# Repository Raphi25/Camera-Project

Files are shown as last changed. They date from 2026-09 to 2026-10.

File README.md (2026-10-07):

# Camera-Project
This master's project investigates the development of a low-cost wearable camera system intended to support caregivers by capturing images throughout the wearer's daily life. The system can take images in 30 second intervals in different settings while remaining lightweight, robust, serviceable, inexpensive and long battery life.

## Current firmware and shared App

The current firmware is in [Development Board Prototype/Code](Development%20Board%20Prototype/Code) and [Breadboard Prototype/Code](Breadboard%20Prototype/Code). Open either Code folder and build with `idf.py build`. Dependencies are restored by the ESP-IDF component manager; generated build output and Python environments are excluded.

Both projects use the single [App](App) folder. Run its `Setup_App.cmd` and `Launch_Source.cmd`, or build the Windows executable with `Build_GUI_App.cmd`. Each firmware folder also has launch and build shortcuts. Local passwords and settings are not part of the repository.

## Architecture

Explore the system, firmware, and desktop application interactively:

[Open the interactive architecture explorer](https://raphi25.github.io/Camera-Project/project-architecture.html)

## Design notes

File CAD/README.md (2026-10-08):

This folder contains the STL gcode files needed to make the PCB Case.

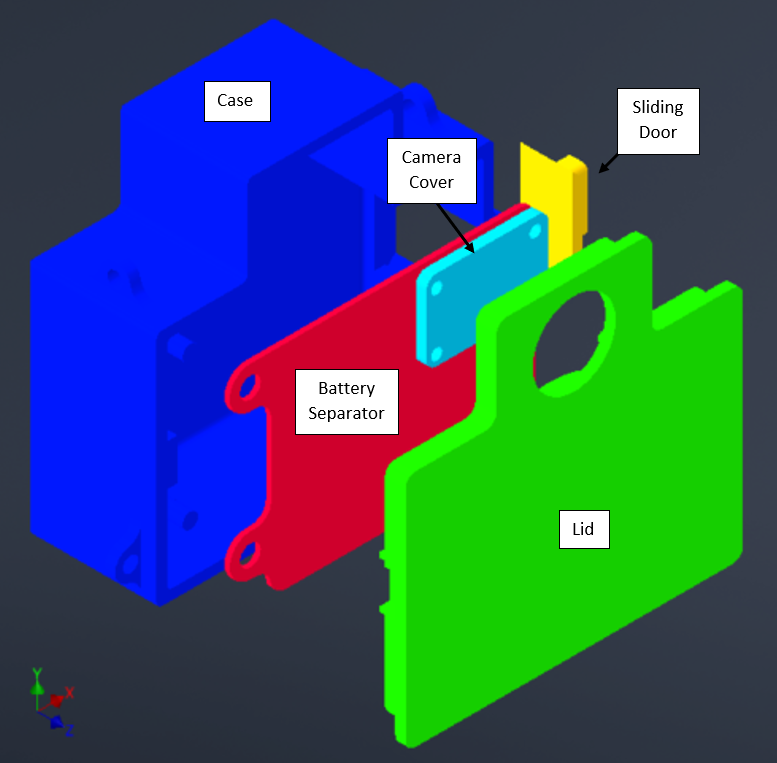
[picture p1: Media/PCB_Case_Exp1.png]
PCB Case


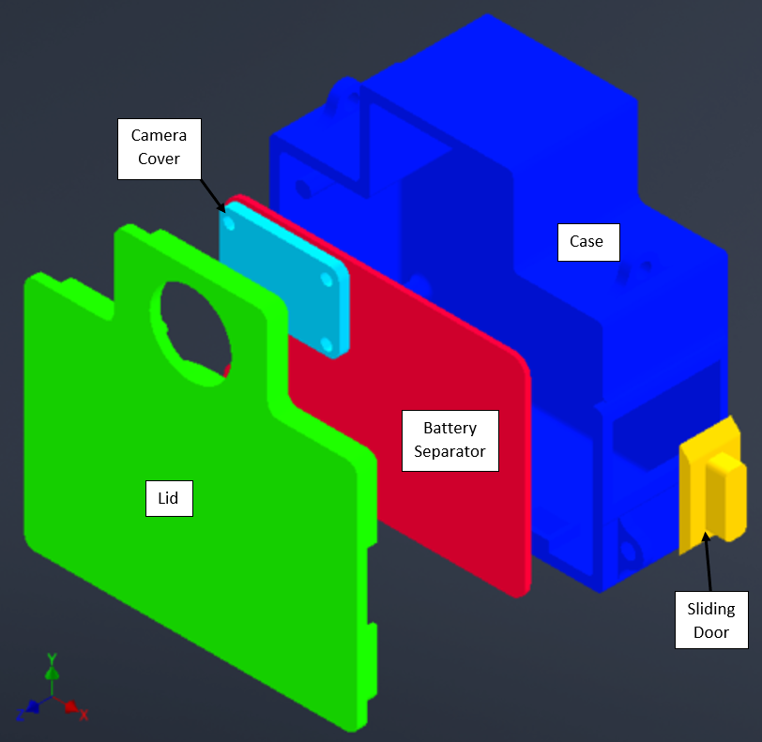
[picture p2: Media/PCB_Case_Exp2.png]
PCB Case


To insert the magnet and receiver coil into teh Lid of teh PCB Case, the print has to be paused at 79-80% percent, pay attention close attention when the 3D printer.

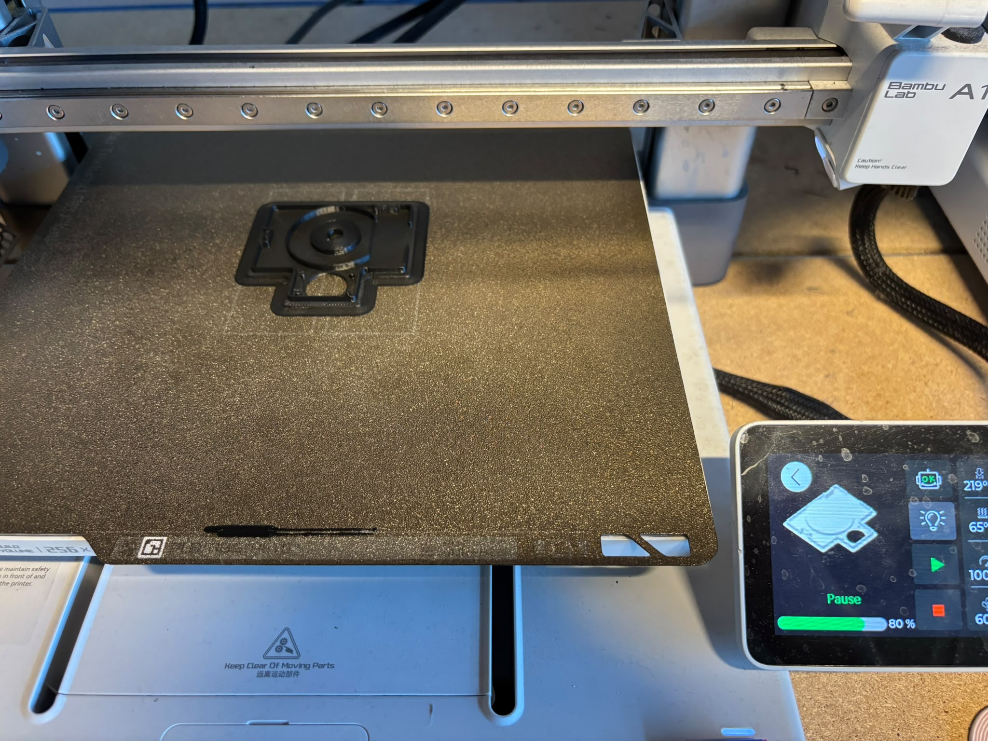
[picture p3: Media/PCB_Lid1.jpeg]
Pause Lid print


The magnet should be able to fit into the central hole and the wireless coil needs to be gently press fitted into the print.

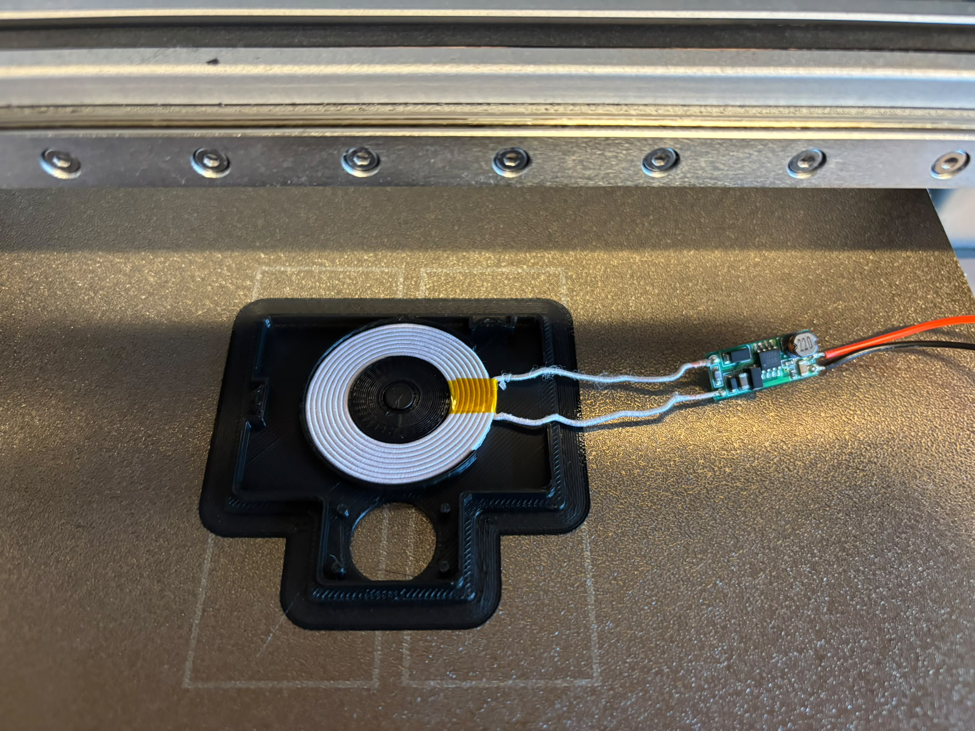
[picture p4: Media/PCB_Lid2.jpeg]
Insert magnet and receiver coil


Once that is done, resume the printing process.

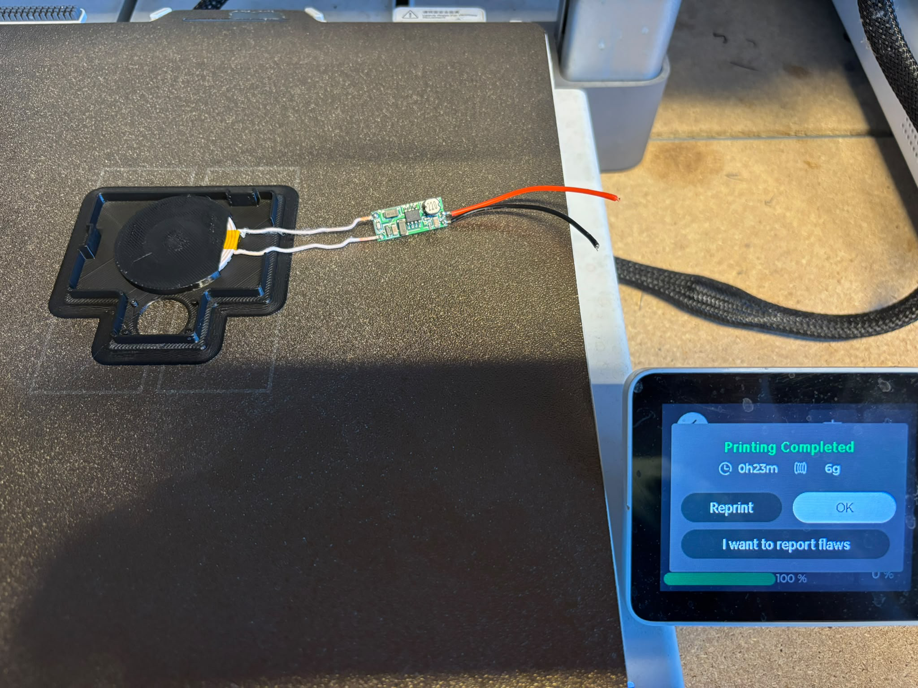
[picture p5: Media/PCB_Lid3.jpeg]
Resume print


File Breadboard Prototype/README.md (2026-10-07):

This folder contains the Code, BOM, storage test results, CAD file for the camera module holder, as well as the code and results for the Blur test.

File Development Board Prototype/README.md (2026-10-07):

This folder contains the Code, BOM, storage test results, CAD files for the case, as well as the code and results for the IMU test.

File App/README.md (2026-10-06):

Shared Camera App
=================

This folder contains the single desktop application used by both sibling
firmware projects: Development Board Prototype and Breadboard Prototype. It will also be the single desktop application used by PCA once its delivered and up and running.

RUN
Double-click Launch_GUI.cmd or BreadboardCameraGUI.exe. Python and ESP-IDF
are not required for the packaged executable. Both firmware projects also
contain Launch_GUI.cmd shortcuts to this same application. On a fresh
installation without a password store, the initial password is ChangeMe123!.

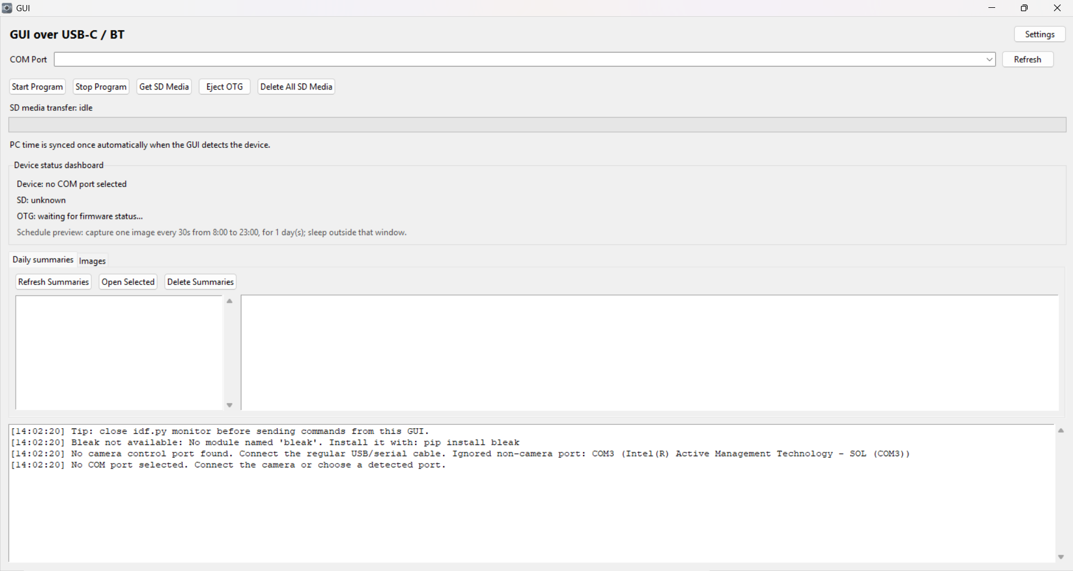
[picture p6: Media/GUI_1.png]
GUI main screen


Select the connected board's COM port or BLE connection inside the app. Click refresh, it will automatically detect the project with an ESP32-P4, no project selection is required.

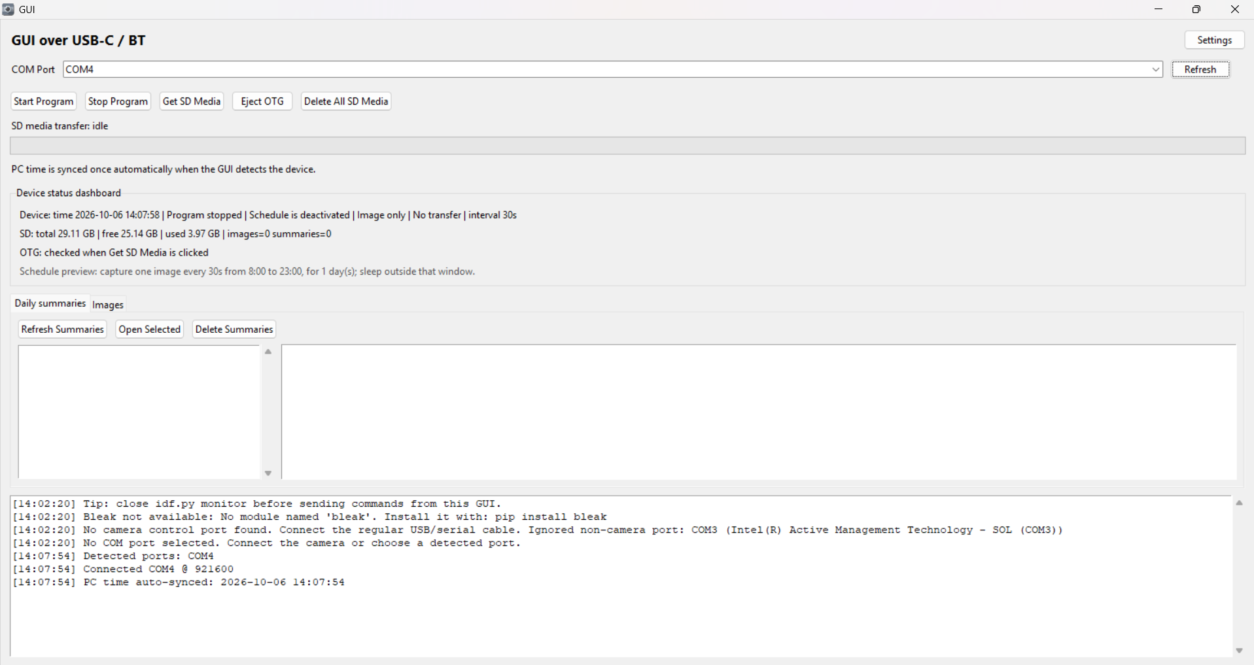
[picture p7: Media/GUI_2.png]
GUI main screen after board is detected


Once project is detected, the Device status dashboard will show the device time, wether a programm is active or not, the schedule of the device, the capture interval. Next, the GUI shows the total free and used space on sd card, and how many images and summaries are already present. Below that teh GUI shows wether the device has an OTG cable attached, for rapid transfer of files.

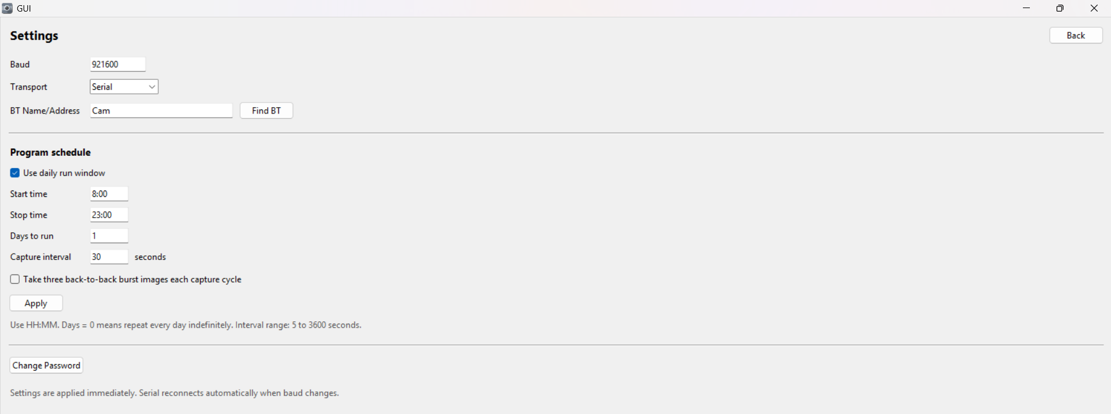
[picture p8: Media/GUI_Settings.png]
GUI settings


When clicking on Settings, certain parameters can be configured, such as mode of transport, Bluetooth name, Program schedule, and wheveer the device should be in normal mode or burst mode. Clicking Apply will confirm teh schedule.

Password can also be changed. Password is needed to login and the transfer or deletion of imagesa and summaries.

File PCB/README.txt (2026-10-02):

This folder contains the Schematic, PCB design and BOM of the device, as well as the datasheets of the parts used for the PCB.

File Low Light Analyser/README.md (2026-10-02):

# OV5647 low-light image analysis

Run the full pipeline with the dataset's current location and the default centered 50% crop:

```powershell
python analyze_low_light.py
```

Use a different normalized crop (`x y width height`) or output folder:

```powershell
python analyze_low_light.py --crop 0.35 0.35 0.30 0.30 --output my_results
```

The script expects one folder per lux level, named like `35LUX`. Each folder can contain any positive number of images; different lux folders may have different image counts. It creates per-image and per-lux CSV files, a formatted Excel workbook with charts, a PNG quality plot, average images, and repeat-standard-deviation maps. Between-repeat standard deviation is unavailable for a folder containing only one image.

Noise is estimated from the high-frequency residual after Gaussian smoothing. This reduces contamination by broad scene gradients, though textured content can still increase the estimate. Repeat variability is pixelwise standard deviation across unregistered repeats, so the camera and scene should remain fixed.

## Separate grayscale and colour-chart analysis

The chart analyzer is a practical, separate-chart, ISO 19093-inspired workflow. It does not claim full ISO 19093 conformity.

Arrange captures as follows:

```text
chart_dataset/
  grayscale/35LUX/image1.jpg ... image5.jpg
  grayscale/75LUX/image1.jpg ... image5.jpg
  colorchecker/35LUX/image1.jpg ... image5.jpg
  colorchecker/75LUX/image1.jpg ... image5.jpg
```

Edit `chart_config.json` so each chart's four normalized corner coordinates describe, in order, its top-left, top-right, bottom-right and bottom-left corners. Coordinates range from 0 to 1 relative to image width and height. The supplied defaults are placeholders. Use the generated diagnostic overlays to confirm every numbered ROI lies inside the intended patch.

Run without calibrated references:

```powershell
python analyze_test_charts.py "C:\path\to\chart_dataset"
```

Run with calibrated patch data:

```powershell
python analyze_test_charts.py "C:\path\to\chart_dataset" `
  --gray-reference grayscale_reference.csv `
  --color-reference color_reference.csv
```

Copy and complete `grayscale_reference_template.csv` with measured relative luminance or reflectance. Copy and complete `color_reference_template.csv` with measured CIELAB reference values. OECF exposure-proxy columns and ΔE76 are only produced when those references are supplied.

Outputs include per-image patch measurements, lux/patch summaries, grayscale OECF/noise/SNR plots, colour chroma/noise/SNR/ΔE plots, diagnostic patch overlays, CSV files and a formatted Excel workbook.

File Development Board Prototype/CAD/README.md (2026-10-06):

This folder contains the STL and gcode files needed to construct the Case for the Development Board Prototype.

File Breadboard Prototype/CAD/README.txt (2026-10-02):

Servo Top is used for Image Quality Test and Blur Test.
For Blur Test, fit the piece on the servo hand.

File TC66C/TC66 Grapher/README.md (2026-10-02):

# TC66 Grapher

Graphs `Current (A)` over `Time` from TC66 CSV or Excel recordings. It also
creates a text report containing the minimum, maximum,
average, total current drawn, projected consumption per 24 hours, and separate
time-weighted average currents while the camera is active and asleep. CSV,
XLSX, XLSM, and legacy XLS files are supported.

Camera state is determined from the configured daily schedule. By default, the
camera is asleep from 23:00 until 08:00 and active from 08:00 until 23:00. To
use a different schedule:

```powershell
.\.venv\Scripts\python.exe plot_tc66.py recording.csv --sleep-start 22:30 --sleep-end 07:30
```

If a sampling interval crosses a scheduled transition, the calculation splits
that interval at the transition. The report shows the measured duration of
each state alongside its average current.

The graph labels every hour on the X-axis.

The recording is automatically cut off at battery shutdown. Shutdown is
detected when voltage is at or below 0.05 V and current is at or below 0.001 A
for 10 consecutive samples. Once confirmed, the cutoff moves back through the
immediately preceding zero-current samples to the first shutdown sample. The
shutdown samples and all later data are excluded from both the graph and
summary statistics.

## Setup

```powershell
python -m venv .venv
.\.venv\Scripts\python.exe -m pip install -r requirements.txt
```

## Run

With no arguments, the newest recording in `Excel files` is used:

```powershell
.\.venv\Scripts\python.exe plot_tc66.py
```

Or choose a file and output path:

```powershell
.\.venv\Scripts\python.exe plot_tc66.py "Excel files\2026-08-20.csv" --output tc66_graph.png
```

The graph defaults to `<input>_graph.png` and the report defaults to
`<input>_summary.txt`. Choose a different report path with `--summary`.

For an Excel workbook, the first sheet is used by default. Select another sheet
by name or zero-based index:

```powershell
.\.venv\Scripts\python.exe plot_tc66.py recording.xlsx --sheet Measurements
```

The input must contain the columns `Time`, `Voltage (V)`, and `Current (A)`.

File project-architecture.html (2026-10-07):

DEVELOPMENT BOARD PROTOTYPE 1

# How the camera system fits together

Explore the hardware, capture pipeline, and desktop application. Select a component to see its role and source files.

Control & applicationCapture & hardwareStorage & filesDashed connection = optional, currently disabled

Current behavior · 7 October 2026

Stop Program: pause → wait for capture and saves → write summary. Burst: three images with individual orientation samples. Repeated summaries: preserve earlier orientation entries. GUI: shared in ../App.

Scroll to zoom · Drag background to pan · Click a component for details

SYSTEM CONTEXT

## An autonomous camera

Works offline. Each view can be exported as a vector SVG. Original architecture notes (September 2026) →

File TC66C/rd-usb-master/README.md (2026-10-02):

Web GUI for RuiDeng USB testers (UM34C, UM24C, UM25C, TC66C)
==

Simple web GUI written in Python 3. Measurements are stored in sqlite database. Tables and graphs are supported.
Live preview and graphing is also available.

Tested on UM34C/UM24C/UM25C/TC66C.

Based on https://github.com/sebastianha/um34c

Requirements
--

- UM34C/UM24C/UM25C - meter connected via regular Bluetooth
- TC66C - meter is using BLE instead of regular bluetooth so pairing will not work nor RFCOMM will
    - BLE has limited support on desktop devices, see used library for supported platforms and versions:
      https://github.com/hbldh/bleak#features
- TC66C USB - meter connected with USB
    - Meter connected with USB exposes itself as serial port
- UM34C/UM24C/UM25C Serial/COM port method - meter can be connected as serial port
    - Pairing with Windows Settings works fine. Pin is 1234. After successful pairing some serial ports are
      installed. In my case two. One of them works.
    - On Linux `rfcomm` and `hcitool` can be used (both provided by bluez package)
        - Retrieve bluetooth address with `hcitool scan`
        - Bind retrieved address to serial port with `rfcomm bind 0 aa:bb:cc:dd:ee:ff`.
          This step is not persistent. Serial port will disappear after reboot. Also, rd-usb needs to
          have permissions to use /dev/rfcommX.

Installation
--

### Binaries (Win x64 only)

- Download from [releases](https://github.com/kolinger/rd-usb/releases)
    - **rd-usb-x.exe** is CLI web server application. GUI is provided by web browser.
      Run executable and web server will be shortly spawned on address http://127.0.0.1:5000.
    - **rd-usb-install-x.exe** is installer of standalone GUI application. Works without web browser.
      Embedded browser is used instead. External web browser still can be used with address (see above).
- Application will be probably blocked by Microsoft SmartScreen. For unblock click `More info`
  and `Run anyway`. I don't have certificate for signing and application does not have any
  reputation so Microsoft will block by default.

### Source code

1. Python 3.11 or newer is required
2. Download `rd-usb-source-x.zip` from [releases](https://github.com/kolinger/rd-usb/releases)
   or `git clone https://github.com/kolinger/rd-usb.git`
3. Install requirements
    - For GUI: `pip install -r requirements.txt`
    - For headless `pip install -r requirements_headless.txt` this version doesn't
      contain dependencies for embedded browser GUI. This is useful if you plan to use CLI/webserver only.
      It's also useful on ARM SBCs.
    - If you encounter failing installing of `pendulum` library then you may need different set of requirements.
      [See bellow for details](#pendulum-issue).\
      In this case use `pip install -r requirements_headless_new.txt` as workaround.
    - If you encounter failing installation of `pybluez` then make sure you have `libbluetooth` dependency installed.\
      For Debian based distribution this means `apt-get install libbluetooth-dev`.\
      For Windows you need Microsoft Visual C++ 14.0 or greater distributed via 
      [Microsoft C++ Build Tools](https://visualstudio.microsoft.com/visual-cpp-build-tools/).
    - There is also currently issue with `pybluez` installation where it fails due to pip version. 
      Make sure you are not using pip 24.x or newer, pip 23.x works fine, if you have newer pip version you can
      downgrade to latest 23.x for example `C:\Python\python.exe -m pip install --upgrade pip==23.3.2`
4. Run with `python web.py` - this will spawn web server on http://127.0.0.1:5000, port can be changed
   with first argument: `python web.py 5555`

For additional arguments/options use --help: `python web.py --help`.

On Windows `python` can be found in Python's installation folder as `python.exe`.
For example replace `python web.py` with `C:\Python\python.exe web.py`
and `pip install -r requirements.txt` with `C:\Python\python.exe -m pip install -r requirements.txt`.

On Linux use `python3` and `pip` inside [virtual environment](https://docs.python.org/3/library/venv.html) (venv).

Usage
--

**UM34C/UM24C/UM25C Bluetooth**

1. Select your device version.
2. Name your session. For example 'testing some power bank'. This is
   used to separate multiple measurements from each other.
3. Select sample rate. Faster sample rate will result in more accurate data but also
   will create a lot more data. For short measurements use faster sample rate. For longer
   use slower rate. Choose carefully.
4. Select UM34C/UM24C/UM25C from devices and follow with Setup link.
    1. If previously connected you can initiate Setup again by clicking on current Bluetooth address
5. Scan for devices and select your device from list by clicking on it
6. After this you can connect simply by using Connect button. Setup is required only for new/different device.
7. Connection will be hopefully successful, and you will see live measurements in graph.
   Otherwise, read log for error messages.

The 100ms and 250ms polling period (‘sample rate’) is misleading since only some meters support polling this quick,
and it seems that all meters have estimated internal sample rate of 2 Hz (500ms) thus even if the meter supports
polling at 10 Hz / 100ms (like the TC66C over USB, while the UM24/25/34 has estimated polling rate up to 3 Hz) this
isn't useful since the extra samples are just duplicates of previous sample. In the original implementation the
polling period wasn't polling period but the gap between samples, that's why in past the 100ms/250ms value did have
meaningful purpose, but currently these options are essentially without purpose and left as legacy.

**TC66C Bluetooth**

1. Make sure your OS is supported and has bluetooth with BLE support (Bluetooth Low Energy)
2. Rest is same as other devices. See above.

**Bluetooth issues**

If you have Bluetooth issues then try to close rd-usb, unplug/plug USB meter and start rd-usb again. Bluetooth can be
sometimes funny and just refuses to work without any reason. If this doesn't help check proximity of your PC and USB
meter, sometimes moving USB meter real close can resolve Bluetooth issues.

Also make sure no other connection to the meter exists, like no other application is connected to the meter,
the RFCOMM isn't bound, if any other connection exists this may break the ability to use or even see the meter
from rd-usb.

If you find trouble connecting to the UM34C/UM24C/UM25C via the direct Bluetooth method then try
to use the UMxxC Serial method, where you need to first pair (in Windows) or use rfcomm bind (Linux),
see [Requirements](#Requirements) above for details.

**TC66C USB or UM34C/UM24C/UM25C Serial/COM port method**

1. Select UM34C/UM24C/UM25C with Serial suffix.
2. Follow Setup link to find your serial port or click Connect if you already have port selected.
3. Rest is same as other devices. See above.

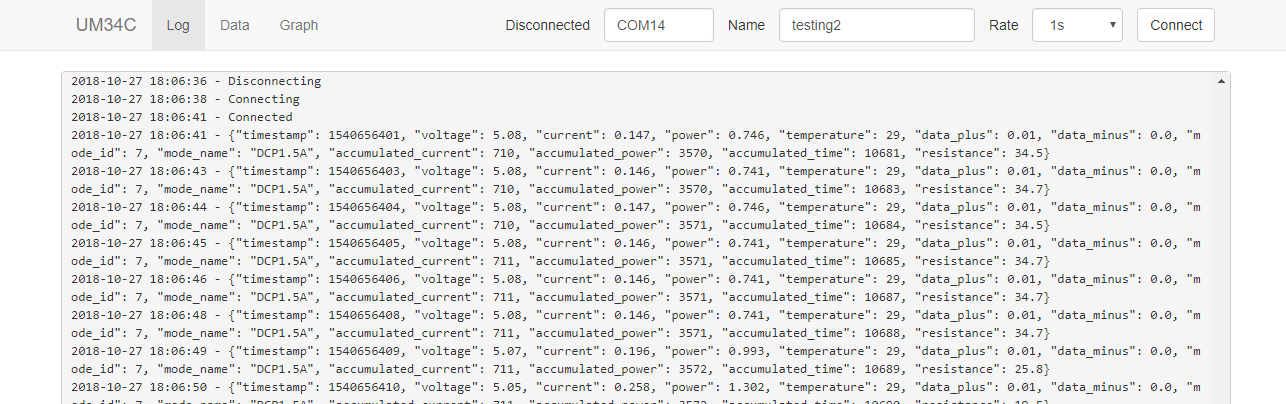
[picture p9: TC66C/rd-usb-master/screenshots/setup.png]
setup


Graphs
--

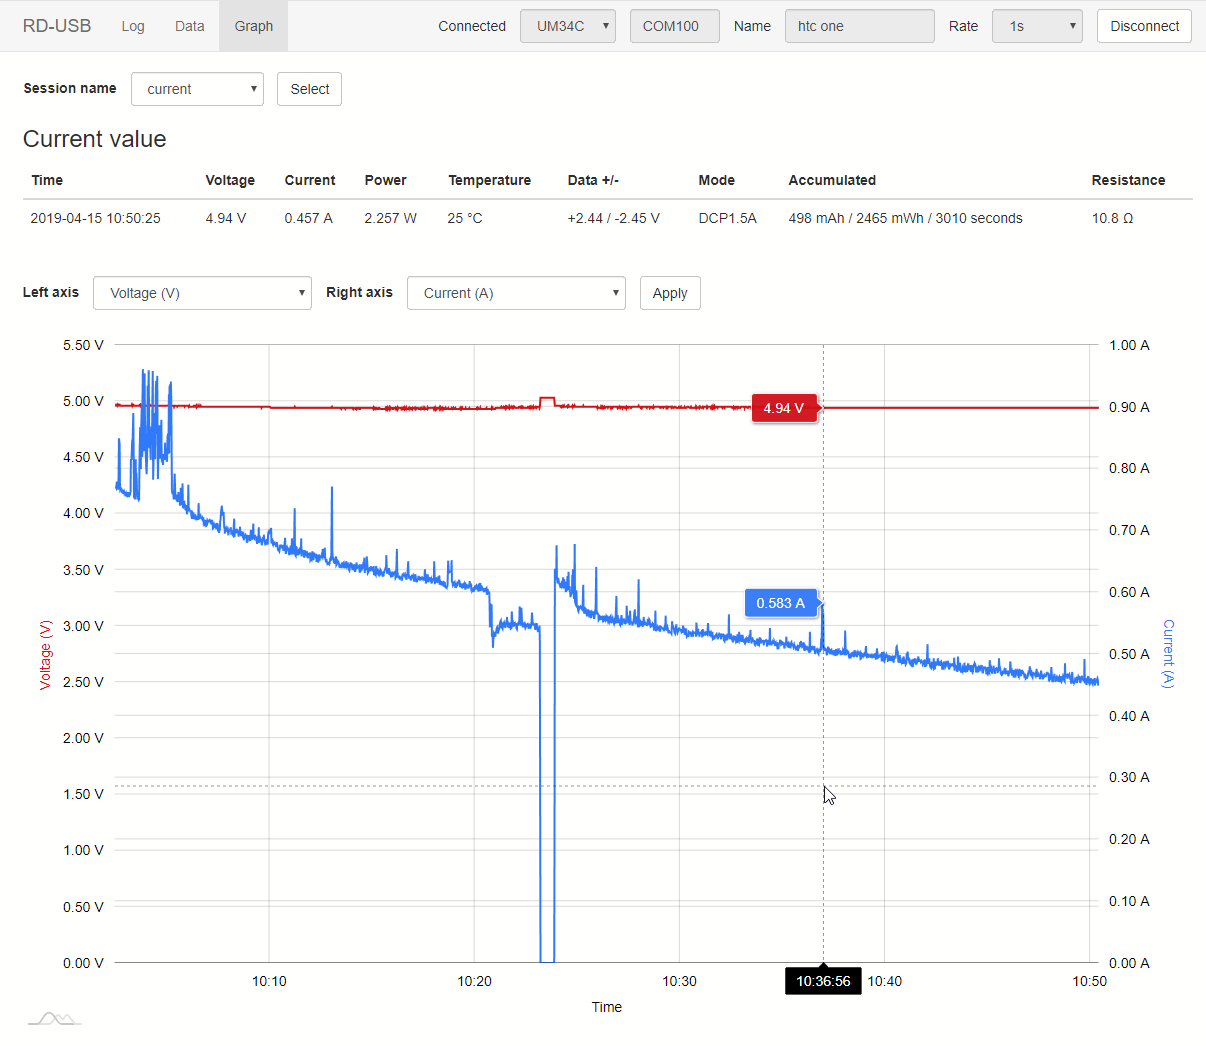
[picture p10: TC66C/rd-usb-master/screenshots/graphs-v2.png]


Tables
--

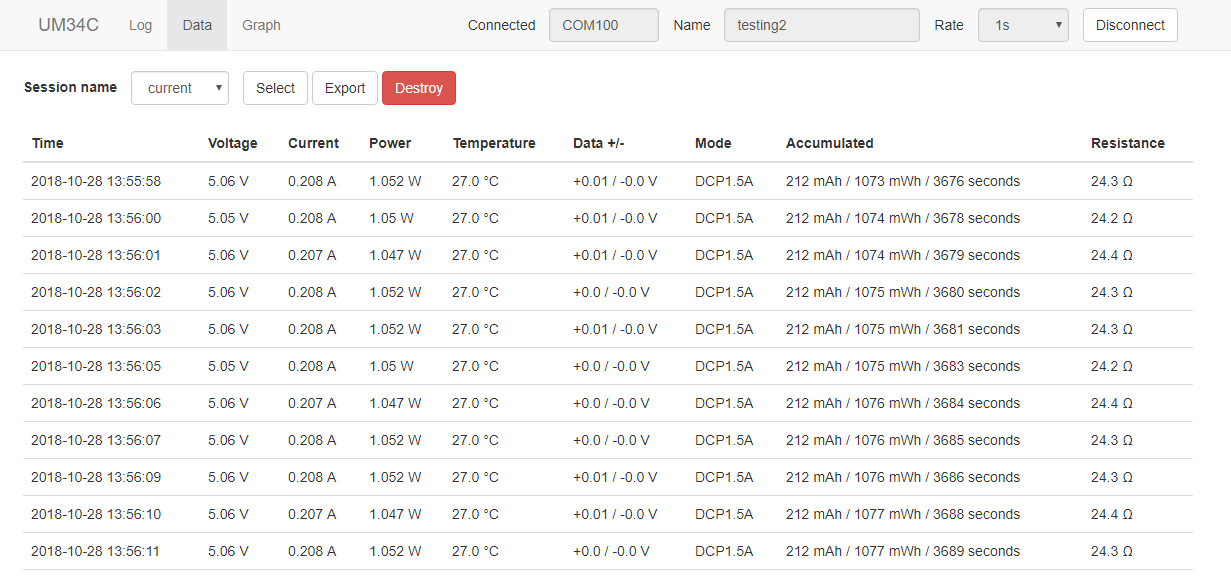
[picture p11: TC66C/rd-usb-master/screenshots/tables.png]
tables


Pendulum issue
--------------

There is known issue with library named `pendulum` (used for date and time) when used together with 
newer Python versions. This issue is triggered when installing requirements via pip and looks
something like this:

```
...
Building wheel for pendulum (pyproject.toml) did not run successfully.
...
ModuleNotFoundError: No module named 'distutils'
...
```

If your installation via pip fails due to this then the solution is to install different version of dependencies.
Specifically `pip install -r requirements_headless_new.txt` should fix this issue.

This issue is solved with version `>=3.0.0` of this library. Unfortunately as of now
version `3.0.0` has other compatibility issues (specifically failing Rust compilation
on systems that don't have prebuilt wheels) thus that's why `<3.0.0` is used by default.

Multiple instances
------------------

If you want to use multiple instances for multiple USB meters then you need to do some adjustments to separate these
instance from each other. As default all instances share the same port thus you can't use multiple USB meters.

This can be easily fixed by changing the port, the port is first argument, without any argument `5000` is used.
We can use default `5000` for first instance and then increment port for each additional instance.

Examples:
- `"C:\Program Files\rd-usb\rd-usb.exe" 5001` for Windows GUI
- `"C:\somewhere\rd-usb.exe" 5001` for Windows standalone binary
- `"C:\Python\python.exe" web.py 5001` for Windows Python
- `/some/python web.py 5001` for Linux

This way you can use multiple instances with multiple USB meters but all data and settings are shared together.

It may be beneficial to separate instances completely including all data and settings. For this extra parameter
`--data-dir` is required, for details see **Custom data directory** section bellow. This parameter expects directory
where all data and settings will be placed. If you combined `--data-dir` and port then you can have independent
instances.

Examples:
- `"C:\Program Files\rd-usb\rd-usb.exe" 5001 --data-dir C:\some\place\for\data` for Windows GUI
- `"C:\somewhere\rd-usb.exe" 5001 --data-dir C:\some\place\for\data` for Windows standalone binary
- `"C:\Python\python.exe web.py" 5001 --data-dir C:\some\place\for\data` for Windows Python
- `/some/python web.py 5001 --data-dir /some/place/for/data` for Linux

On Windows it may be handy to make shortcut for this - just copy existing shortcut and add the parameters at the end of
Target field separated by space like the first examples. Then you have easy access to your second instance.

Docker
--

Experimental Docker container exists. Bluetooth isn't officially supported in Docker so there is need to pass special
arguments to Docker to make it work - there are also caveats that different system may need extra system changes to
make Bluetooth in Docker work.

**Ubuntu/Debian/Raspbian caveats** - you need to load custom Docker AppArmor policy and add extra argument for Docker 
to use this policy instead of the default one. 

In terminal:
```
sudo wget https://raw.githubusercontent.com/kolinger/rd-usb/master/docker/docker-ble -O /etc/apparmor.d/docker-ble
sudo apparmor_parser -r -W /etc/apparmor.d/docker-ble
```

This may be sometimes unnecessary, but it won't hurt.
Thanks to @thijsputman for his work on [docker-ble](https://github.com/thijsputman/tc66c-mqtt/blob/main/docker/docker-ble).

**Other Linuxes caveats** - unknown - if you know, let me know. The principe is the same but details may differ. 
If you use AppArmor then you may need custom policy otherwise Bluetooth won't work.

**Don't forget** to mount `/opt/rd-usb/data` via volume otherwise you will lose all your data when container gets 
recreated/updated.

**docker-compose.yml**

```
version: '3.7'
services:
  rd-usb:
    container_name: rd-usb
    image: kolinger/rd-usb:latest
    restart: unless-stopped
    security_opt:
      - apparmor=docker-ble
    environment:
      - TZ=Etc/UTC # change your timeozne (TZ identifier here), for example Europe/London
      - ARGS=
    volumes:
      - /var/run/dbus/system_bus_socket:/var/run/dbus/system_bus_socket
      - /some/place/to/store/data:/opt/rd-usb/data
    # you need something like these examples if you want to use serial port based communication
    #devices:
    #  - /dev/ttyUSB0
    #  - /dev/rfcomm0
    network_mode: host
```

Change `/some/place/to/store/data` to your liking.

If you want to use TC66C USB or UMxxC Serial then you also need to pass specific serial device to docker. For TC66C USB
it would be something like /dev/ttyUSB0 and for UMxxC Serial something like /dev/rfcomm0.

Optional arguments for `web.py` can be passed to `ARGS` environment variables - for example `ARGS=1888` will 
change listening port to 1888, `ARGS="1888 --prefix /rd-usb"` will set path prefix for proxy purposes.

Custom data directory
--
Custom data directory can be specified with `--data-dir` option.

For example `rd-usb.exe --data-dir C:/rd-usb` will place all configuration and data files in `C:/rd-usb` directory.
This can be used together with shortcut, just make sure you escape path with quotes properly, for example:
`"C:\your\path\rd-usb.exe" --data-dir "C:\your\path\data"`.

Custom export
--

Application has basic CSV export built-in. For more advanced use-cases external script can be used.

External program/script can be specified with `--on-receive` option.
This script will be executed when new data is received.
New measurements are provided as JSON file. Path of this file is provided as first argument.

For managing overhead another option `--on-receive-interval` is available (default value is 60).
This number specified how often is external script called (in seconds, default value is every minute).
Value 0 means script will be called for every new measurement as they happen.
Script is not called when no new measurements are available.

CLI example: `python web.py --on-receive on-receive.sh`

See `on-receive.sh` or `on-receive.cmd` files for more information how implement this program/script.
Also `on-receive-python-example.cmd` and `on-receive-python-example.py` show more extended example how to call python.

Example structure of JSON file:

```
[
    {
        "timestamp": 1599556295,
        "voltage": 5.12,
        "current": 0.0,
        "power": 0.0,
        "temperature": 25,
        "data_plus": 0.0,
        "data_minus": 0.0,
        "mode_id": 7,
        "mode_name": "DCP1.5A",
        "accumulated_current": 0,
        "accumulated_power": 0,
        "accumulated_time": 0,
        "resistance": 9999.9,
        "name": "measurement name"
    },
    ...
]
```

Reverse proxy
--

If you like to have HTTPS (or use reverse proxy for other reasons) then simple reverse proxy can be used.
All common webservers can do this. Here are examples for nginx.

You can also modify on what address/interface is rd-usb listening by providing `--listen` CLI option
like `--listen 192.168.1.100` where `192.168.1.100` is address of interface you want to listen on.

At root:

````
server {
	listen 443 ssl;
	listen [::]:443 ssl;

	ssl_certificate /your/certificate.crt;
	ssl_certificate_key /your/certificate.key;

	server_name rd-usb;

	location / {
		proxy_pass http://127.0.0.1:5000;
	}
}
````

In path:

````
server {
	listen 443 ssl;
	listen [::]:443 ssl;

	ssl_certificate /your/certificate.crt;
	ssl_certificate_key /your/certificate.key;

	server_name domain.tld;

	# your other things

	location /rd-usb {
		proxy_pass http://127.0.0.1:5000;
	}
}
````

When some prefix/path is used then it needs to be specified as argument `--prefix` when launching rd-usb.
In this example `--prefix /rd-usb` is required resulting in something like `python3 web.py --prefix /rd-usb`.

Note: `rd-usb` should not be exposed on untrusted network or to untrusted users.
Use [HTTP basic auth](https://docs.nginx.com/nginx/admin-guide/security-controls/configuring-http-basic-authentication/)
for example as authentication mechanism when running rd-usb at untrusted network.

Systemd service
--

If you would like to have rd-usb start automatically on unix systems, you can grab the example service files,
drop them in `/etc/systemd/system/` respectively:

/etc/systemd/system/rfcomm0.service

```
[Unit]
Description=rfcomm0
After=bluetooth.target

[Service]
Type=oneshot
User=root
ExecStart=/usr/bin/rfcomm bind 0 <METER_BT_MAC_ADDRESS>
ExecStart=/usr/bin/chown root:dialout /dev/rfcomm0
ExecStop=/usr/bin/rfcomm release 0
RemainAfterExit=yes
Restart=no

[Install]
WantedBy=multi-user.target
```

```
systemctl enable rfcomm0.service
systemctl start rfcomm0.service
```

/etc/systemd/system/rd-usb.service

```
[Unit]
Description=rd-usb
After=network.target
After=rfcomm0.service

[Service]
Type=simple
WorkingDirectory=</path/to/rd-usb>
ExecStart=/usr/bin/python3 web.py --daemon
User=www-data
Group=www-data
Restart=always
RestartSec=30

[Install]
WantedBy=multi-user.target
```

```
systemctl enable rd-usb.service
systemctl start rd-usb.service
```

Don't forget to add user of `rd-usb.service` to `dialout` group to enable access to `/dev/rfcomm0` for communication.
In this example you need to add `www-data` to `dialout` like this `usermod -aG dialout www-data`.
Webserver as reverse proxy in front of `rd-usb.service` is suggested (like nginx, apache2, ...).

Development
--

### Building binaries

1. Install pyinstaller: `pip install pyinstaller` (4.x) and [NSIS](https://nsis.sourceforge.io/Download) installer
2. Generate binaries:
    - `pyinstaller pyinstaller-cli.spec`
    - `pyinstaller pyinstaller.spec`
    - `makensis.exe installer.nsi`
    - or use `build.cmd`
3. Binaries will be saved in `dist` directory

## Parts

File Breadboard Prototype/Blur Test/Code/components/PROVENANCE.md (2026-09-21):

# Camera stack provenance

Copied from the local `Breadboard Prototype - SC2336` on 2026-09-06.
Directory names omit the `espressif__` registry prefix so ESP-IDF can resolve
the component dependencies with its component manager disabled.

- esp_cam_sensor 2.3.0: original project's local component, including its patches.
- esp_video 2.3.0, esp_ipa 2.2.0~1, esp_sccb_intf 0.0.8 and cmake_utilities:
  original project's managed components; version metadata is retained.

The OV5647 driver file was SHA-256 identical in both source projects.
`main/ov5647_custom.json` was copied from the OV5647 prototype.
Third-party licenses and component manifests are retained in each directory.

Local change: `esp_ipa/CMakeLists.txt` and `tools/config/esp_ipa_config.py` pass
and accept multiple separately quoted JSON paths. This fixes building both
sensor profiles together in a Windows workspace whose path contains spaces.
Legacy semicolon-separated input remains accepted.

TinyUSB additions copied from the same local prototype on 2026-09-08:
- esp_tinyusb 2.2.1 (commit 8e779566ef71d43928cbf7e125e8eb54bab3f542).
- tinyusb 0.21.0~1 (commit 7049c58a0e895acc92c6407574b05b5536eddfc8).
The existing esp_tinyusb CMake dependency declaration for disabled component
manager is retained. License files are included in both components.

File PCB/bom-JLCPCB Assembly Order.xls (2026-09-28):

JLCPCB BOM Tool - BOM Matching
BOM name：bom-JLCPCB Assembly Order.xlsx |  |  | Download Time：2026-09-27 21:30:55 |  |  |  | * Our matching results are updated in real-time, but stock and prices may change. If it's been over 24 hours, please re-match before placing your order.
PCB Assembled Qty：5 |  |  | Est. Total Price：204.3983
Your BOM |  |  |  | Matched Parts |  |  |  |  |  |  | Order Information
Designator | Comment | Footprint | JLCPCB Part # | Matches | Part # | Manufacturer | Footprint | Description | Category | Warning | JLCPCB Part # | Product link | Lib Type | Qty | Source | Total Price ($)
BAT1 | 3000 | BAT-SMD_CR1202 |  | Select by System | 3000 | Keystone | - | - ROHS | Battery Connector |  | C238097 | https://jlcpcb.com/partdetail/Keystone-3000/C238097 | Extended | 5 | 5 JLCPCB | 1.6975
C21,C27,C3,C31,C32,C33,C34,C35,C43,C45,C46,C47,C5,C50,C12,C14,C16,C2,C23,C24,C25,C28,C7,C9 | 100nF | 0402 |  | Select by System | CL05B104KO5NNNC | Samsung Electro-Mechanics | 0402 | 100nF 16V X7R ±10% 0402 Multilayer Ceramic Capacitors MLCC - SMD/SMT ROHS | Multilayer Ceramic Capacitors MLCC - SMD/SMT |  | C1525 | https://jlcpcb.com/partdetail/1877-CL05B104KO5NNNC/C1525 | Basic | 140 | 140 JLCPCB | 0.63
C22,C49,C10,C13,C15,C17,C18,C19,C20,C26,C48,C6 | 1uF | 0402 |  | Select by System | CL05A105KA5NQNC | Samsung Electro-Mechanics | 0402 | 1uF 25V X5R ±10% 0402 Multilayer Ceramic Capacitors MLCC - SMD/SMT ROHS | Multilayer Ceramic Capacitors MLCC - SMD/SMT |  | C52923 | https://jlcpcb.com/partdetail/53938-CL05A105KA5NQNC/C52923 | Basic | 80 | 80 JLCPCB | 0.792
C29,C30 | 18pF | 0402 |  | Select by System | 0402CG180J500NT | FH (Guangdong Fenghua Advanced Tech) | 0402 | 18pF 50V C0G ±5% 0402 Multilayer Ceramic Capacitors MLCC - SMD/SMT ROHS | Multilayer Ceramic Capacitors MLCC - SMD/SMT |  | C1549 | https://jlcpcb.com/partdetail/1901-0402CG180J500NT/C1549 | Basic | 20 | 20 JLCPCB | 0.068
C36,C44,C11,C8 | 10nF | 0402 |  | Select by System | CL05B103KB5NNNC | Samsung Electro-Mechanics | 0402 | 10nF 50V X7R ±10% 0402 Multilayer Ceramic Capacitors MLCC - SMD/SMT ROHS | Multilayer Ceramic Capacitors MLCC - SMD/SMT |  | C15195 | https://jlcpcb.com/partdetail/15869-CL05B103KB5NNNC/C15195 | Basic | 40 | 40 JLCPCB | 0.2
C37,C39 | 4.7uF | 0402 |  | Select by System | CL05A475MP5NRNC | Samsung Electro-Mechanics | 0402 | 10V 4.7uF X5R ±20% 0402 Multilayer Ceramic Capacitors MLCC - SMD/SMT ROHS | Multilayer Ceramic Capacitors MLCC - SMD/SMT |  | C23733 | https://jlcpcb.com/partdetail/24469-CL05A475MP5NRNC/C23733 | Basic | 20 | 20 JLCPCB | 0.332
C38,C4,C40,C41,C42,C1 | 10uF | 0402 |  | Select by System | CL05A106MQ5NUNC | Samsung Electro-Mechanics | 0402 | 10uF 6.3V X5R ±20% 0402 Multilayer Ceramic Capacitors MLCC - SMD/SMT ROHS | Multilayer Ceramic Capacitors MLCC - SMD/SMT |  | C15525 | https://jlcpcb.com/partdetail/16204-CL05A106MQ5NUNC/C15525 | Basic | 55 | 55 JLCPCB | 1.4025
D1 | USBLC6-2SC6 | SOT-23-6_L2.9-W1.6-P0.95-LS2.8-BL |  | Select by System | USBLC6-2SC6 | STMicroelectronics | SOT-23-6L | -40℃~+125℃ 150nA 17V 2 3.5pF 5.25V 5A 6V ESD IEC 61000-4-2 Unidirectional SOT-23-6L ESD and Surge Protection (TVS/ESD) ROHS | ESD And Surge Protection (TVS/ESD) |  | C7519 | https://jlcpcb.com/partdetail/STMicroelectronics-USBLC62SC6/C7519 | Extended | 7 | 7 JLCPCB | 1.2355
D2,D3 | PMEG2010ER-TP | SOD-123F_L2.7-W1.7-LS3.6-RD |  | Select by System | PMEG2010ER-TP | TECH PUBLIC | SOD-123F | -65℃~+125℃ 1 Independent 12A 1A 1mA@20V 20V 360mV@1A SOD-123F Schottky Diodes ROHS |  |  | C49231019 | https://jlcpcb.com/partdetail/TECHPUBLIC-PMEG2010ERTP/C49231019 | Extended | 12 | 12 JLCPCB | 1.1304
FPC1 | 1.0-15P下接 | FPC-SMD_C66660 |  | Select by System | 1.0-15P下接 | BOOMELE(Boom Precision Elec) | SMD,P=1mm,卧贴 | -25℃~+85℃ 0.3mm 15P 1mm 2.46mm 500mA 50V Bottom Contact Slide Lock Surface Mount, Right Angle SMD,P=1mm,卧贴 FFC, FPC (Flat Flexible) Connector Assemblies ROHS | FFC, FPC (Flat Flexible) Connector Assemblies |  | C66660 | https://jlcpcb.com/partdetail/BOOMELE_Boom_Precision_Elec-1_0_15P/C66660 | Extended | 5 | 5 JLCPCB | 0.589
LED1,LED2,LED3,LED4,LED5 | 16-213SURC/S530-A4/TR8 | LED0402-R-RD |  | Select by System | 16-213SURC/S530-A4/TR8 | Everlight Elec | 0402 | -40℃~+85℃ 1.7V~2.4V 120° 20mA 36mcd~50mcd 60mW 624nm 632nm Discrete Diode Red Water Clear 0402 LED Indication - Discrete ROHS | LED Indication - Discrete |  | C74339 | https://jlcpcb.com/partdetail/EverlightElec-16_213SURC_S530_A4TR8/C74339 | Extended | 33 | 33 JLCPCB | 1.0263
Q1,Q2 | AO3401A_C306862 | SOT-23-3_L2.9-W1.3-P1.90-LS2.4-BR |  | Select by System | AO3401A | BORN | SOT-23 | 1 P-Channel 1.4W 115pF 2V 30V 4.2A 85mΩ@2.5V 954pF P-Channel SOT-23 MOSFETs ROHS | MOSFETs |  | C306862 | https://jlcpcb.com/partdetail/BORN-AO3401A/C306862 | Extended | 14 | 14 JLCPCB | 0.8344
R2,R3 | 4.02kΩ | 0402 |  | Select by System | RC0402FR-074K02L | YAGEO | 0402 | -55℃~+155℃ 4.02kΩ 50V 62.5mW Thick Film Resistor ±1% ±100ppm/℃ 0402 Chip Resistor - Surface Mount ROHS | Chip Resistor - Surface Mount |  | C137968 | https://jlcpcb.com/partdetail/YAGEO-RC0402FR074K02L/C137968 | Extended | 20 | 20 JLCPCB | 0.042
R10,R13,R14,R16,R17,R18,R19,R20,R36,R4,R41,R42,R5,R9,R1,R32,R34 | 10kΩ | 0402 |  | Select by System | 0402WGF1002TCE | UNI-ROYAL(Uniroyal Elec) | 0402 | -55℃~+155℃ 10kΩ 50V 62.5mW Thick Film Resistor ±1% ±100ppm/℃ 0402 Chip Resistor - Surface Mount ROHS | Chip Resistor - Surface Mount |  | C25744 | https://jlcpcb.com/partdetail/26487-0402WGF1002TCE/C25744 | Basic | 105 | 105 JLCPCB | 0.357
R11 | 5.1kΩ | 0402 |  | Select by System | 0402WGF5101TCE | UNI-ROYAL(Uniroyal Elec) | 0402 | -55℃~+155℃ 5.1kΩ 50V 62.5mW Thick Film Resistor ±1% ±100ppm/℃ 0402 Chip Resistor - Surface Mount ROHS | Chip Resistor - Surface Mount |  | C25905 | https://jlcpcb.com/partdetail/26648-0402WGF5101TCE/C25905 | Basic | 20 | 20 JLCPCB | 0.048
R12,R15,R6 | 51kΩ | 0402 |  | Select by System | 0402WGF5102TCE | UNI-ROYAL(Uniroyal Elec) | 0402 | -55℃~+155℃ 50V 51kΩ 62.5mW Thick Film Resistor ±1% ±100ppm/℃ 0402 Chip Resistor - Surface Mount ROHS | Chip Resistor - Surface Mount |  | C25794 | https://jlcpcb.com/partdetail/26537-0402WGF5102TCE/C25794 | Basic | 25 | 25 JLCPCB | 0.0475
R21 | 450kΩ | 0402 |  | Select by System | FRC0402F4503TS | FOJAN | 0402 | -55℃~+155℃ 450kΩ 50V 62.5mW Thick Film Resistor ±1% ±100ppm/℃ 0402 Chip Resistor - Surface Mount ROHS | Chip Resistor - Surface Mount |  | C5159688 | https://jlcpcb.com/partdetail/FOJAN-FRC0402F4503TS/C5159688 | Extended | 20 | 20 JLCPCB | 0.034
R22,R23,R24,R25 | 100kΩ | 0402 |  | Select by System | 0402WGF1003TCE | UNI-ROYAL(Uniroyal Elec) | 0402 | -55℃~+155℃ 100kΩ 50V 62.5mW Thick Film Resistor ±1% ±100ppm/℃ 0402 Chip Resistor - Surface Mount ROHS | Chip Resistor - Surface Mount |  | C25741 | https://jlcpcb.com/partdetail/26484-0402WGF1003TCE/C25741 | Basic | 30 | 30 JLCPCB | 0.075
R26 | 1.6kΩ | 0402 |  | Select by System | 0402WGF1601TCE | UNI-ROYAL(Uniroyal Elec) | 0402 | -55℃~+155℃ 1.6kΩ 50V 62.5mW Thick Film Resistor ±1% ±100ppm/℃ 0402 Chip Resistor - Surface Mount ROHS | Chip Resistor - Surface Mount |  | C4908 | https://jlcpcb.com/partdetail/5316-0402WGF1601TCE/C4908 | Extended | 20 | 20 JLCPCB | 0.032
R27 | 910Ω | 0402 |  | Select by System | FRC0402F9100TS | FOJAN | 0402 | -55℃~+155℃ 50V 62.5mW 910Ω Thick Film Resistor ±1% ±100ppm/℃ 0402 Chip Resistor - Surface Mount ROHS | Chip Resistor - Surface Mount |  | C2909392 | https://jlcpcb.com/partdetail/FOJAN-FRC0402F9100TS/C2909392 | Extended | 20 | 20 JLCPCB | 0.036
R28,R29 | 150Ω | 0402 |  | Select by Customer | 0402WGF1500TCE | UNI-ROYAL(Uniroyal Elec) | 0402 | -55℃~+155℃ 150Ω 50V 62.5mW Thick Film Resistor ±1% ±100ppm/℃ 0402 Chip Resistor - Surface Mount ROHS | Chip Resistor - Surface Mount |  | C25082 | https://jlcpcb.com/partdetail/25825-0402WGF1500TCE/C25082 | Extended | 20 | 20 JLCPCB | 0.034
R30 | 50kΩ | 0402 |  | Select by System | RTT025002FTH | RALEC | 0402 | -55℃~+155℃ 50V 50kΩ 62.5mW Thick Film Resistor ±1% ±100ppm/℃ 0402 Chip Resistor - Surface Mount ROHS | Chip Resistor - Surface Mount |  | C166559 | https://jlcpcb.com/partdetail/RALEC-RTT025002FTH/C166559 | Extended | 20 | 20 JLCPCB | 0.022
R31 | 750Ω | 0402 |  | Select by System | 0402WGF7500TCE | UNI-ROYAL(Uniroyal Elec) | 0402 | -55℃~+155℃ 50V 62.5mW 750Ω Thick Film Resistor ±1% ±100ppm/℃ 0402 Chip Resistor - Surface Mount ROHS | Chip Resistor - Surface Mount |  | C25132 | https://jlcpcb.com/partdetail/25875-0402WGF7500TCE/C25132 | Extended | 20 | 20 JLCPCB | 0.024
R33 | 24.9kΩ | 0402 |  | Select by System | RC0402FR-0724K9L | YAGEO | 0402 | -55℃~+155℃ 24.9kΩ 50V 62.5mW Thick Film Resistor ±1% ±100ppm/℃ 0402 Chip Resistor - Surface Mount ROHS | Chip Resistor - Surface Mount |  | C138027 | https://jlcpcb.com/partdetail/YAGEO-RC0402FR0724K9L/C138027 | Extended | 20 | 20 JLCPCB | 0.034
R35 | 15kΩ | 0402 |  | Select by System | 0402WGF1502TCE | UNI-ROYAL(Uniroyal Elec) | 0402 | -55℃~+155℃ 15kΩ 50V 62.5mW Thick Film Resistor ±1% ±100ppm/℃ 0402 Chip Resistor - Surface Mount ROHS | Chip Resistor - Surface Mount |  | C25756 | https://jlcpcb.com/partdetail/26499-0402WGF1502TCE/C25756 | Basic | 20 | 20 JLCPCB | 0.032
R37 | 330Ω | 0402 |  | Select by System | 0402WGF3300TCE | UNI-ROYAL(Uniroyal Elec) | 0402 | -55℃~+155℃ 330Ω 50V 62.5mW Thick Film Resistor ±1% ±100ppm/℃ 0402 Chip Resistor - Surface Mount ROHS | Chip Resistor - Surface Mount |  | C25104 | https://jlcpcb.com/partdetail/25847-0402WGF3300TCE/C25104 | Basic | 20 | 20 JLCPCB | 0.08
R38,R39,R7,R8 | 2.2kΩ | 0402 |  | Select by System | 0402WGF2201TCE | UNI-ROYAL(Uniroyal Elec) | 0402 | -55℃~+155℃ 2.2kΩ 50V 62.5mW Thick Film Resistor ±1% ±100ppm/℃ 0402 Chip Resistor - Surface Mount ROHS | Chip Resistor - Surface Mount |  | C25879 | https://jlcpcb.com/partdetail/26622-0402WGF2201TCE/C25879 | Basic | 30 | 30 JLCPCB | 0.159
R40 | 4.7kΩ | 0402 |  | Select by System | 0402WGF4701TCE | UNI-ROYAL(Uniroyal Elec) | 0402 | -55℃~+155℃ 4.7kΩ 50V 62.5mW Thick Film Resistor ±1% ±100ppm/℃ 0402 Chip Resistor - Surface Mount ROHS | Chip Resistor - Surface Mount |  | C25900 | https://jlcpcb.com/partdetail/26643-0402WGF4701TCE/C25900 | Basic | 20 | 20 JLCPCB | 0.054
R43,R44,R45 | 3.3kΩ | 0402 |  | Select by System | 0402WGF3301TCE | UNI-ROYAL(Uniroyal Elec) | 0402 | -55℃~+155℃ 3.3kΩ 50V 62.5mW Thick Film Resistor ±1% ±100ppm/℃ 0402 Chip Resistor - Surface Mount ROHS | Chip Resistor - Surface Mount |  | C25890 | https://jlcpcb.com/partdetail/26633-0402WGF3301TCE/C25890 | Basic | 25 | 25 JLCPCB | 0.0875
SD1 | 503398-1892 | TF-SMD_503398-1892 |  | Select by System | 5033981892 | MOLEX | SMD | -25℃~+85℃ 1.28mm Connector and Ejector MicroSD Card (TF Card) Push-Push SMD SD Card / Memory Card Connector ROHS | SD Card / Memory Card Connector |  | C428492 | https://jlcpcb.com/partdetail/MOLEX-5033981892/C428492 | Extended | 5 | 5 JLCPCB | 5.676
SW1,SW2 | 1TS026A-1000-0550-CT | SW-SMD_4P-L2.6-W1.6-P0.75-LS3.0 |  | Select by System | 1TS026A-1000-0550-CT | HYP (Hongyuan Precision) | SMD-4P,2.6x1.6mm | -40℃~+90℃ 0.55mm 1.6mm 12V 1N 2.6mm 200,000 Cycles 50mA Black IP68 No Round Button SMD(SMT) Tab SPST Surface Mount,Vertical Without Bracket SMD-4P,2.6x1.6mm Tactile Switches ROHS | Tactile Switches |  | C913778 | https://jlcpcb.com/partdetail/984195-1TS026A_1000_0550CT/C913778 | Extended | 13 | 13 JLCPCB | 1.3533
U2 | W25Q128JVSIQ | SOIC127P790X216-8N |  | Select by System | W25Q128JVSIQ | Winbond Elec | SOIC-8-208mil | -40℃~+85℃ 100,000 cycles 120ms@(32KB) 128Mbit 133MHz 1uA 2.7V~3.6V 20 Years 3ms Power-on reset、Hardware write protection、Software write protection、Write enable latch、Absolute write protection SPI SOIC-8-208mil NOR FLASH ROHS | NOR FLASH |  | C97521 | https://jlcpcb.com/partdetail/WinbondElec-W25Q128JVSIQ/C97521 | Basic | 5 | 5 JLCPCB | 12.748
U3,U4 | TLV62569PDRLR | SOT-563_L1.6-W1.2-P0.50-LS1.6-BL |  | Select by System | TLV62569PDRLR | Texas Instruments | SOT-563 | -40℃~+125℃@(TJ) 1 1.5MHz 2.5V~5.5V 2A 35uA 600mV~5.5V Adjustable Buck Buck Built-in Yes SOT-563 DC-DC Converters ROHS | DC-DC Converters |  | C398364 | https://jlcpcb.com/partdetail/TexasInstruments-TLV62569PDRLR/C398364 | Extended | 10 | 10 JLCPCB | 1.61
U5,U6 | XAL4020-222MEC | IND-SMD_L4.0-W4.0-A |  | Select by System | XAL4020-222MEC | Coilcraft | SMD,4x4mm | 2.2uH 35.2mΩ 5.5A 5.6A ±20% SMD,4x4mm Power Inductors ROHS | Power Inductors |  | C3151182 | https://jlcpcb.com/partdetail/Coilcraft-XAL4020222MEC/C3151182 | Extended | 10 | 10 JLCPCB | 93.133
U7 | BQ24074RGTR | QFN-16_L3.0-W3.0-P0.50-TL-EP1.7 |  | Select by System | BQ24074RGTR | Texas Instruments | QFN-16-EP(3x3) | -40℃~+125℃ 1 1.5A 4.2V 4.35V~10.2V 6.5uA Charging IC Lithium Battery Not supported Support QFN-16-EP(3x3) Battery Management ROHS | Battery Management |  | C54313 | https://jlcpcb.com/partdetail/TexasInstruments-BQ24074RGTR/C54313 | Extended | 5 | 5 JLCPCB | 12.5045
U8 | SM03B-SRSS-TB | CONN-SMD_SM03B-SRSS-TB-LF-SN-P |  | Select by System | SM03B-SRSS-TB(LF)(SN) | JST | SMD,P=1mm,卧贴 | -25℃~+85℃ 1 1A 1mm 1x3P 2.9mm 3 3P 4.32mm 50V 5mm Auxiliary Solder Pin Copper alloy PA SH Surface Mount, Right Angle Tin UL94V-0 White SMD,P=1mm,卧贴 Wire To Board Connector ROHS | Wire To Board Connector |  | C160403 | https://jlcpcb.com/partdetail/JST-SM03B_SRSS_TB_LF_SN/C160403 | Extended | 5 | 5 JLCPCB | 0.9665
U9 | S2B-PH-K-S | CONN-TH_S2B-PH-K-S-LF-SN |  | Select by System | S2B-PH-K-S(LF)(SN) | JST | 弯插,P=2mm | -25℃~+85℃ 1 100V 1x2P 2 2A 2P 2mm 4.8mm 5.9mm 7.6mm Brass K Pin PA66 PH Right Angle Tin UL94V-0 White 弯插,P=2mm Wire To Board Connector ROHS | Wire To Board Connector |  | C173752 | https://jlcpcb.com/partdetail/JST-S2B_PH_K_S_LF_SN/C173752 | Extended | 5 | 5 JLCPCB | 0.1975
U10 | ESP32-C6-MINI-1-N4 | WIFIM-SMD_61P-L16.6-W13.2-P0.80-ESP32-C6-MINI-1-N4 |  | Select by System | ESP32-C6-MINI-1-N4 | Espressif Systems | SMD-53P | -106dBm -40℃~+85℃ 2.4GHz 21dBm 354mA 3V~3.6V 71mA ESP32-C6FH4 On-board PCB Antenna UART、SPI、I2C、GPIO、I2S SMD-53P WiFi Modules ROHS | WiFi Modules |  | C5736265 | https://jlcpcb.com/partdetail/EspressifSystems-ESP32_C6_MINI_1N4/C5736265 | Extended | 5 | 5 JLCPCB | 19.406
U11 | LSM6DSOTR | LGA-14_L3.0-W2.5-P0.50-TL |  | Select by System | LSM6DSOTR | STMicroelectronics | LGA-14(2.5x3) | -40℃~+85℃ 1.71V~3.6V 9KB Accelerometer Gyroscope SPI、I2C X,Y,Z X,Y,Z ±16g ±2000dps LGA-14(2.5x3) Accelerometers ROHS | Accelerometers |  | C2655100 | https://jlcpcb.com/partdetail/STMicroelectronics-LSM6DSOTR/C2655100 | Extended | 5 | 5 JLCPCB | 19.382
U12 | DS3231MZ+_C722467 | SOIC-8_L4.9-W3.9-P1.27-LS6.0-BL |  | Select by System | DS3231MZ+ | Analog Devices Inc./Maxim Integrated | SOIC-8 | -40℃~+85℃ 2.3V~5.5V I2C Temperature compensation、Backup power management and battery charging、Alarm function、Periodic interrupt output SOIC-8 Real Time Clocks ROHS | Real Time Clocks |  | C722467 | https://jlcpcb.com/partdetail/766565-DS3231MZ/C722467 | Extended | 5 | 5 JLCPCB | 22.1345
USB1 | 2171790001 | USB-C-SMD_2171790001 |  | Select by Customer | 2171790001 | MOLEX | SMD | -40℃~+85℃ 1 10000 times 16P 30V 5A Black Female Type-C USB 2.0 SMD USB Connectors ROHS | USB Connectors |  | C3197684 | https://jlcpcb.com/partdetail/MOLEX-2171790001/C3197684 | Extended | 5 | 5 JLCPCB | 3.4755
Y1 | Crystal_GND24_Small | Crystal_SMD_3225-4Pin_3.2x2.5mm |  | Select by Customer | 3225 40M 12PF 10PPM | SST | SMD3225-4P | -20℃~+70℃ 12pF 40MHz ±10ppm ±30ppm SMD3225-4P Crystals ROHS | Crystals |  | C5380316 | https://jlcpcb.com/partdetail/SST-3225_40M_12PF10PPM/C5380316 | Extended | 9 | 9 JLCPCB | 0.6759
U1 | ESP32-P4NRW32X | QFN-104_L10.0-W10.0-P0.35-TL-EP7.5 |  | Select by System | ESP32-P4NRW32X | Espressif Systems | QFN-104_10x10mm | QFN-104(10x10) Microcontrollers (MCU/MPU/SOC) ROHS |  |  | C54540373 | https://jlcpcb.com/partdetail/EspressifSystems-ESP32P4NRW32X/C54540373 | Extended | 5 | 0 JLCPCB | 0

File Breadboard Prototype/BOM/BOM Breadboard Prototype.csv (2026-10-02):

Product name | Description | Item number | Vendor | Price per unit [Dkk] | Amount | Total price
FireBeetle 2 ESP32-P4 AI Vision Board | Microprocessor | DFR1172 | DFRobot | 155 | 1 | 155
SC2336 | Camera Module |  | Wireless-Tag | 29,56 | 1 | 29,56
Arducam OV5647 | Camera Module | B003504 | Arducam | 157,61 | 1 | 157,61
Adafruit DS3231 Precision RTC Breakout | RTC |  | Amazon | 149,49 | 1 | 149,49
6DOF IMU Sensor | IMU | SEN0693 | DFRobot | 43,95 | 1 | 43,95
Positional Servo |  |  |  |  | 1
Breadboard |  |  |  |  | 1
Male-Female Wires |  |  |  |  | 8
Male-Male Wires |  |  |  |  | 10
Micro SD Card |  |  |  |  | 1
USB-C Cable |  |  |  |  | 1
3V Coin Battery |  |  |  |  | 1
 |  |  |  |  | TOTAL: | 535,61
>>>>>>> 4e19fb1 (Add BOMs, Data for Blur and IMU tests and KiCad 8.0 PCB schematics and layout)

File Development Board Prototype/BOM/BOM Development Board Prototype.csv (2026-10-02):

Product name | Description | Item number | Vendor | Price per unit [Dkk] | Amount | Total price
FireBeetle 2 ESP32-P4 AI Vision Board | Microprocessor | DFR1172 | DFRobot | 105,17 | 1 | 105,17
SC2336 | Camera Module |  | Wireless-Tag | 29,56 | 1 | 29,56
Arducam OV5647 | Camera Module | B003504 | Arducam | 157,61 | 1 | 157,61
Seeed Studio Battery Charger | Battery charger | 287-6437 | RS | 48,57 | 1 | 48,57
Genopladeligt batteri, 3.7 V, Litium-polymer, 1.8 Ah | Lithium Battery | 144-9405 | RS | 109,56 | 1 | 109,56
Adafruit DS3231 Precision RTC Breakout | RTC |  | Amazon | 149,49 | 1 | 149,49
6DOF IMU Sensor | IMU | SEN0693 | DFRobot | 43,95 | 1 | 43,95
Wireless Charging Module 5V/1A | Wireless Charging Module | DFR0362 | DFRobot | 43,95 | 1 | 43,95
PHR 2 | Female Straight Connector Cap 2 mm Pitch, 2-Pole, 1 Row | 820-1466 | RS | 5,9 | 1 | 5,9
Magnets | Neodymium magnet 0.39 kg, W/D: 5 mm | 219-2248 | RS | 75,17 | 1 | 75,17
Male-Male Wires |  |  |  |  | 6
Micro SD Card |  |  |  |  | 1
USB-C Cable |  |  |  |  | 1
3V Coin Battery |  |  |  |  | 1
 |  |  |  |  | TOTAL: | 768,93
>>>>>>> 4e19fb1 (Add BOMs, Data for Blur and IMU tests and KiCad 8.0 PCB schematics and layout)

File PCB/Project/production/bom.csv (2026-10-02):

Designator | Footprint | Quantity | Value | LCSC Part #
BAT1 | BAT-SMD_CR1202 | 1 | 3000 | C238097
C1, C38, C4, C40, C41, C42 | 0402 | 6 | 10uF
C10, C13, C15, C17, C18, C19, C20, C22, C26, C48, C49, C6 | 0402 | 12 | 1uF
C11, C36, C44, C8 | 0402 | 4 | 10nF
C12, C14, C16, C2, C21, C23, C24, C25, C27, C28, C3, C31, C32, C33, C34, C35, C43, C45, C46, C47, C5, C50, C7, C9 | 0402 | 24 | 100nF
C29, C30 | 0402 | 2 | 18pF
C37, C39 | 0402 | 2 | 4.7uF
D1 | SOT-23-6_L2.9-W1.6-P0.95-LS2.8-BL | 1 | USBLC6-2SC6 | C7519
D2, D3 | SOD-123F_L2.7-W1.7-LS3.6-RD | 2 | PMEG2010ER-TP | C49231019
FPC1 | FPC-SMD_C66660 | 1 | 1.0-15P下接 | C66660
J1 | SolderWire-0.1sqmm_1x02_P3.6mm_D0.4mm_OD1mm | 1 | Conn_01x02
LED1, LED2, LED3, LED4, LED5 | LED0402-R-RD | 5 | 16-213SURC/S530-A4/TR8 | C74339
Q1, Q2 | SOT-23-3_L2.9-W1.3-P1.90-LS2.4-BR | 2 | AO3401A_C306862 | C306862
R1, R10, R13, R14, R16, R17, R18, R19, R20, R32, R34, R36, R4, R41, R42, R5, R9 | 0402 | 17 | 10kΩ
R11 | 0402 | 1 | 5.1kΩ
R12, R15, R6 | 0402 | 3 | 51kΩ
R2, R3 | 0402 | 2 | 4.02kΩ
R21 | 0402 | 1 | 450kΩ
R22, R23, R24, R25 | 0402 | 4 | 100kΩ
R26 | 0402 | 1 | 1.6kΩ
R27 | 0402 | 1 | 910Ω
R28, R29 | 0402 | 2 | 150Ω
R30 | 0402 | 1 | 50kΩ
R31 | 0402 | 1 | 750Ω
R33 | 0402 | 1 | 24.9kΩ
R35 | 0402 | 1 | 15kΩ
R37 | 0402 | 1 | 330Ω
R38, R39, R7, R8 | 0402 | 4 | 2.2kΩ
R40 | 0402 | 1 | 4.7kΩ
R43, R44, R45 | 0402 | 3 | 3.3kΩ
SD1 | TF-SMD_503398-1892 | 1 | 503398-1892 | C428492
SW1, SW2 | SW-SMD_4P-L2.6-W1.6-P0.75-LS3.0 | 2 | 1TS026A-1000-0550-CT | C913778
TP1, TP2, TP3 | TestPoint_Pad_1.0x1.0mm | 3 | TestPoint
U1 | QFN-104_L10.0-W10.0-P0.35-TL-EP7.5 | 1 | ESP32-P4NRW32X | C54540373
U10 | WIFIM-SMD_61P-L16.6-W13.2-P0.80-ESP32-C6-MINI-1-N4 | 1 | ESP32-C6-MINI-1-N4 | C5736265
U11 | LGA-14_L3.0-W2.5-P0.50-TL | 1 | LSM6DSOTR | C2655100
U12 | SOIC-8_L4.9-W3.9-P1.27-LS6.0-BL | 1 | DS3231MZ+_C722467 | C722467
U2 | SOIC127P790X216-8N | 1 | W25Q128JVSIQ
U3, U4 | SOT-563_L1.6-W1.2-P0.50-LS1.6-BL | 2 | TLV62569PDRLR | C398364
U5, U6 | IND-SMD_L4.0-W4.0-A | 2 | XAL4020-222MEC | C3151182
U7 | QFN-16_L3.0-W3.0-P0.50-TL-EP1.7 | 1 | BQ24074RGTR | C54313
U8 | CONN-SMD_SM03B-SRSS-TB-LF-SN-P | 1 | SM03B-SRSS-TB | C160403
U9 | CONN-TH_S2B-PH-K-S-LF-SN | 1 | S2B-PH-K-S | C173752
USB1 | USB-C-SMD_2171790001 | 1 | 2171790001 | C3197684
Y1 | Crystal_SMD_3225-4Pin_3.2x2.5mm | 1 | Crystal_GND24_Small

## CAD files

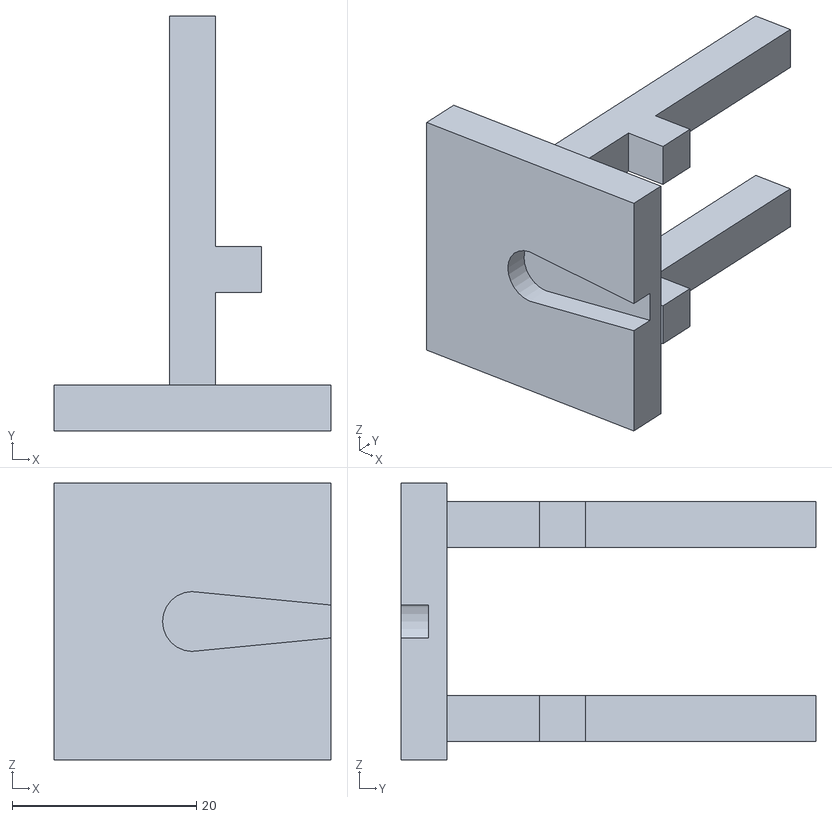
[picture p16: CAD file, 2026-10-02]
Breadboard Prototype/CAD/Servo_Top.stl
30.0 x 45.0 x 30.0

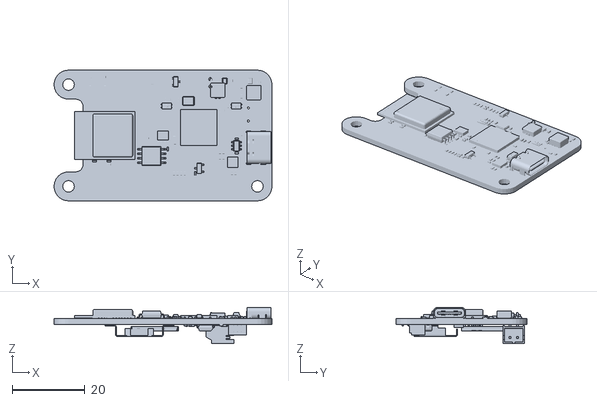
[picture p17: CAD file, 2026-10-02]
PCB/Project/STEP_BLENDER/PCB.stl
60.0 x 36.0 x 10.0

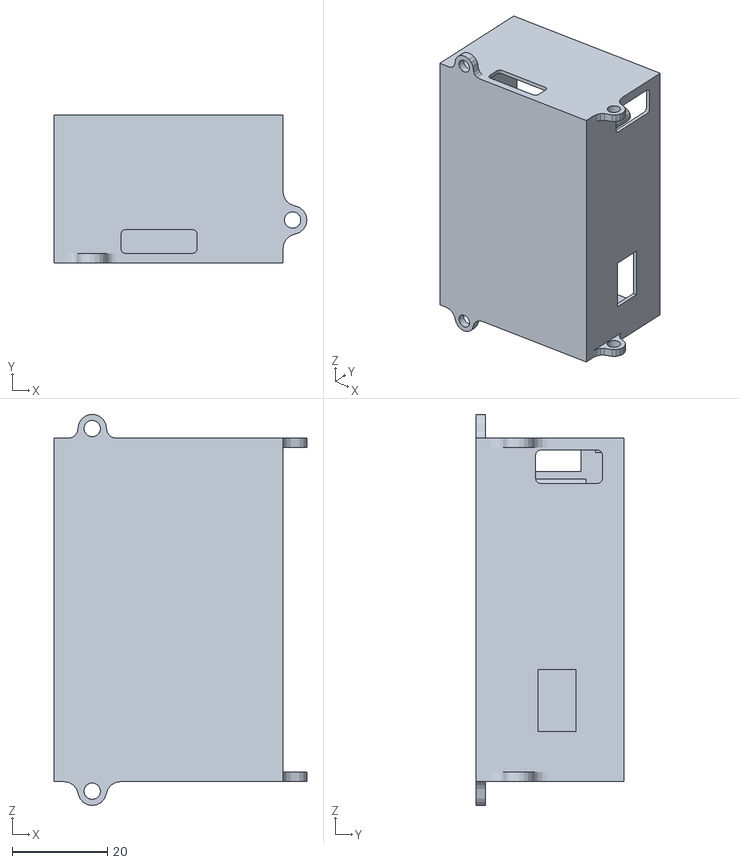
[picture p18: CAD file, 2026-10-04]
Development Board Prototype/CAD/Case.stl
53.0 x 31.0 x 82.0

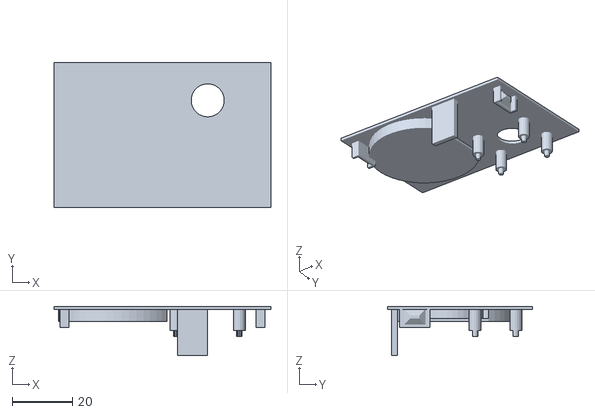
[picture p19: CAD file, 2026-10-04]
Development Board Prototype/CAD/Cover.stl
72.0 x 48.0 x 16.3

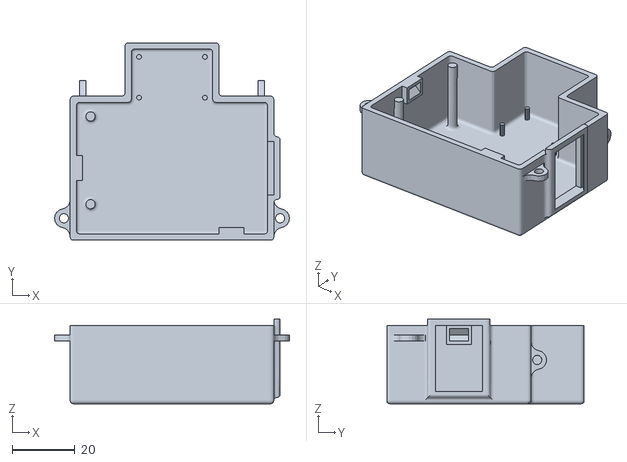
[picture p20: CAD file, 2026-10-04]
CAD/Case.stl
75.0 x 63.0 x 27.0

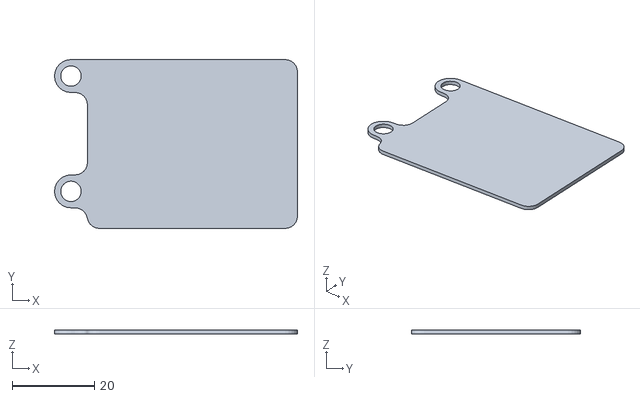
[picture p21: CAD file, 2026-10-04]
CAD/Battery_seperator.stl
59.0 x 41.0 x 1.00

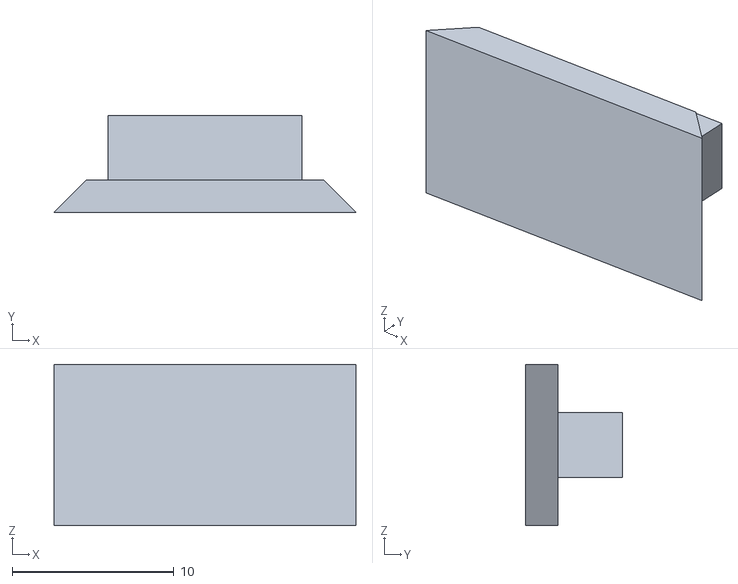
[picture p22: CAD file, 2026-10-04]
CAD/Slidingdoor.stl
18.7 x 6.00 x 10.0

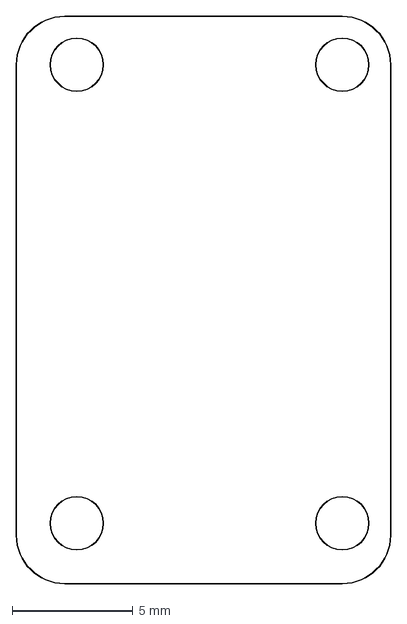
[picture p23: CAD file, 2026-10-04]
CAD/Plastic_cover1.dxf
15.5 x 23.5 mm

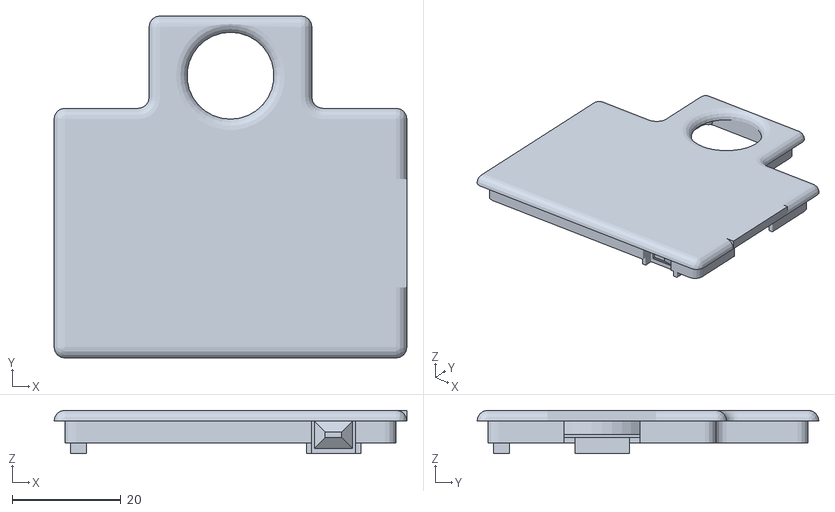
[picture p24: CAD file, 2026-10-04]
CAD/Cover.stl
65.0 x 63.0 x 8.00

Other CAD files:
CAD/Battery_seperator.gcode.3mf
Development Board Prototype/CAD/Lid.gcode.3mf
CAD/Slidingdoor.gcode.3mf
Development Board Prototype/CAD/Case.gcode.3mf
CAD/Case.gcode.3mf
CAD/Lid.gcode.3mf
PCB/Project/STEP_BLENDER/PCB/PCB/3000--3DModel-STEP-630548.iam
PCB/Project/STEP_BLENDER/PCB/PCB/3000.ipt
PCB/Project/STEP_BLENDER/PCB/PCB/7.ipt
PCB/Project/STEP_BLENDER/PCB/PCB/CONN-SMD_SR1.00-WS-3P.iam
PCB/Project/STEP_BLENDER/PCB/PCB/CONN-SMD_SR1.00-WS-3P.ipt
PCB/Project/STEP_BLENDER/PCB/PCB/CONN-TH_HR-PH2.0-WI-2P.iam
PCB/Project/STEP_BLENDER/PCB/PCB/CONN-TH_HR-PH2.0-WI-2P.ipt
PCB/Project/STEP_BLENDER/PCB/PCB/C_0402_1005Metric.iam
PCB/Project/STEP_BLENDER/PCB/PCB/C_0402_1005Metric.ipt
PCB/Project/STEP_BLENDER/PCB/PCB/Crystal_SMD_3225-4Pin_3.2x2.5mm.iam
PCB/Project/STEP_BLENDER/PCB/PCB/Crystal_SMD_3225-4Pin_3.2x2.5mm.ipt
PCB/Project/STEP_BLENDER/PCB/PCB/IND-SMD_L4.0-W4.0-A.iam
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

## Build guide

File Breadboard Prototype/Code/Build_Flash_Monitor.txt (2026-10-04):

Both projects now build with flash encryption disabled.
Use the ESP-IDF 6.0.2 terminal:

idf.py -B build build
idf.py -B build -p COM5 flash
idf.py -B build -p COM5 monitor

These commands assume the board's hardware flash encryption is disabled.
A previously encrypted board needs a separate, verified eFuse transition
before plaintext firmware can boot. Changing sdkconfig does not change eFuses.
The common partition table is at 0xc000; NVS starts at 0xd000.
The development-board NVS address changed from 0xa000, so device settings and
credentials at the old location are not migrated automatically by flashing.
Export/decrypt existing SD media and back up device credentials before flashing
the development board's new layout; newly generated credentials cannot decrypt
media saved using the old credentials.

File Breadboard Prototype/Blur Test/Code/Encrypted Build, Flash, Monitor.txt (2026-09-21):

This project now targets the existing development-encrypted board.
Images saved on the SD card remain ordinary, unencrypted JPEGs.
Exit monitor first with Ctrl+], then open an ESP-IDF terminal in this project.
Use the following commands (replace COM5 if needed):

idf.py -B build build
idf.py -B build -p COM5 encrypted-flash
esptool --chip esp32p4 -p COM5 run
idf.py -B build -p COM5 monitor

Use full encrypted-flash, not encrypted-app-flash, to recover an invalid
bootloader header. Opening monitor alone never installs the new firmware.
If flashing cannot connect: hold BOOT, tap RESET, release BOOT, and retry.
Do not erase flash or change/burn eFuses for this recovery.

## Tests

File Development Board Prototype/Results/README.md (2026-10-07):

This folder contains results from the storage tests for normal and burst mode.

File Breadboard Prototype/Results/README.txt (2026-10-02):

Each folder shows the data collected and it's results.
_L is for long range, _S is short range.

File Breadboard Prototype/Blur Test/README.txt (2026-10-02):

This folder contains the code, results, data for the Blur Test. 
The retrieved images from the test is under code.

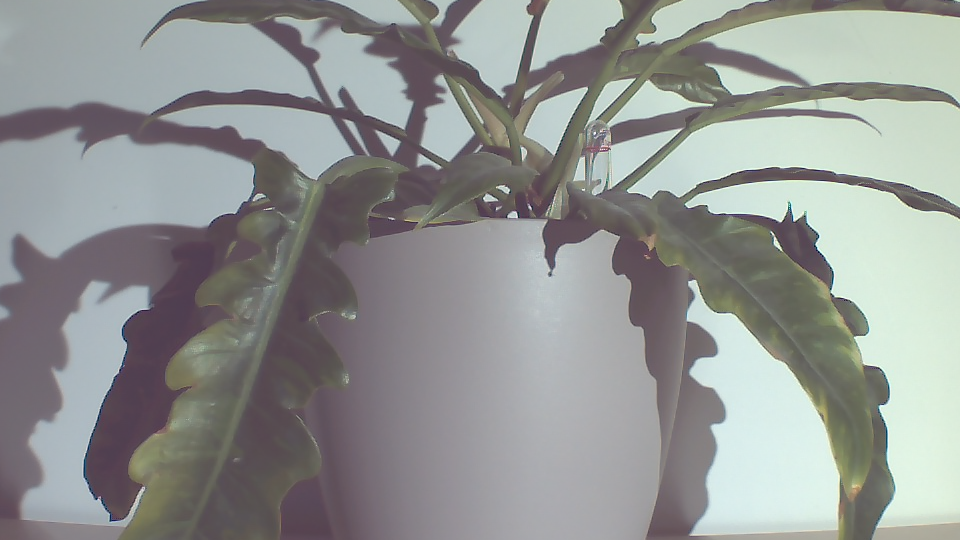
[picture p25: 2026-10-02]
Low Light Analyser/tmp/sc2336_variable_count_test/average_images/600LUX_average.png

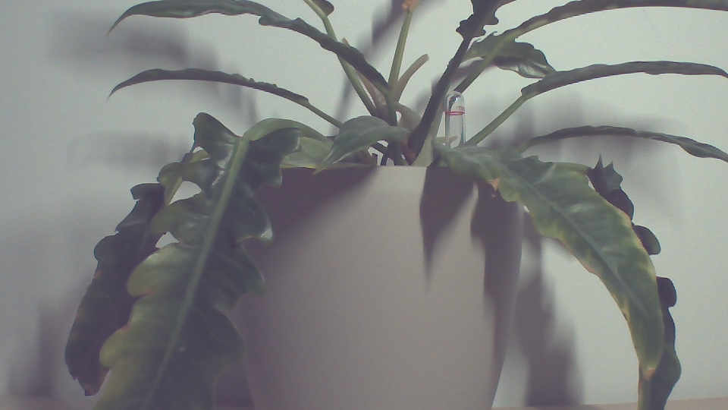
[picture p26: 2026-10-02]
Low Light Analyser/tmp/sc2336_variable_count_test/average_images/10LUX_average.png

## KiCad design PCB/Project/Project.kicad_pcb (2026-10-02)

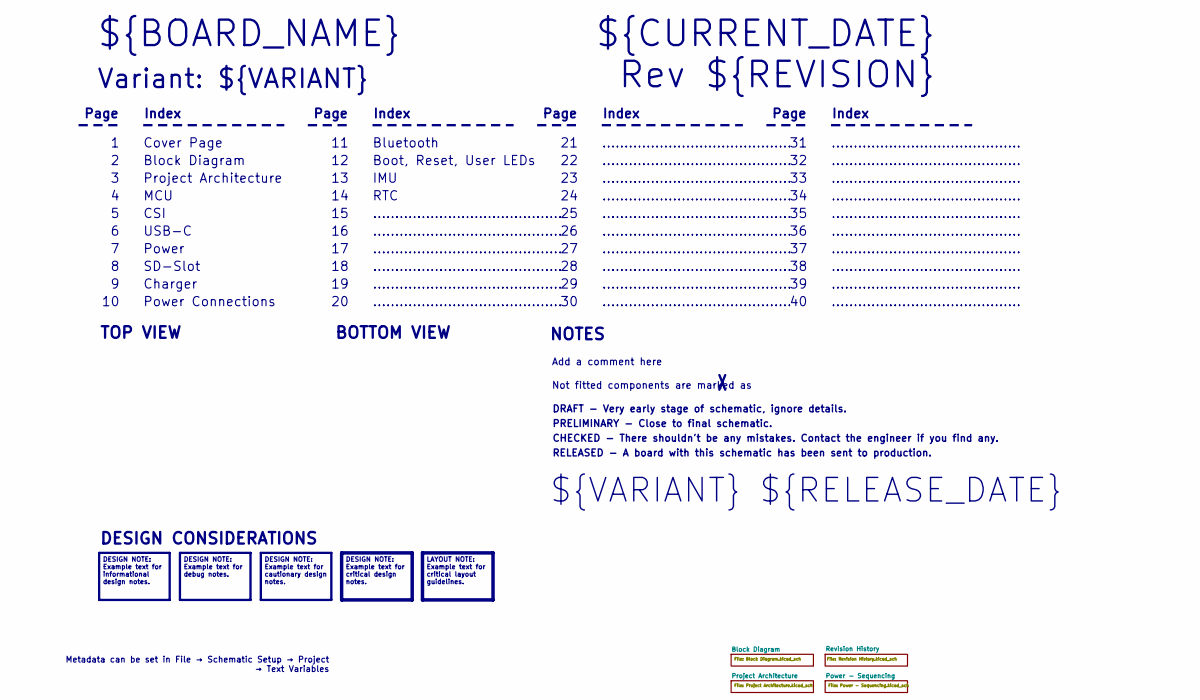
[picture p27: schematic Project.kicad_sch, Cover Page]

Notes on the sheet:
Metadata can be set in File → Schematic Setup → Project → Text Variables
DESIGN NOTE: Example text for informational design notes.
LAYOUT NOTE: Example text for critical layout guidelines.
DESIGN NOTE: Example text for cautionary design notes.
DESIGN NOTE: Example text for debug notes.
DESIGN NOTE: Example text for critical design notes.
BOTTOM VIEW
...........................................
RELEASED - A board with this schematic has been sent to production.
Page
TOP VIEW
Power Connections
Charger
SD-Slot
Not fitted components are marked as
Index
IMU
PRELIMINARY - Close to final schematic.
${VARIANT} ${RELEASE_DATE}
MCU
${CURRENT_DATE}
Variant: ${VARIANT}
Rev ${REVISION}
CSI
Bluetooth
${BOARD_NAME}
DRAFT - Very early stage of schematic, ignore details.
RTC
USB-C
Block Diagram
Add a comment here
Cover Page
NOTES
Boot, Reset, User LEDs
Project Architecture
CHECKED - There shouldn't be any mistakes. Contact the engineer if you find any.
DESIGN CONSIDERATIONS
Power

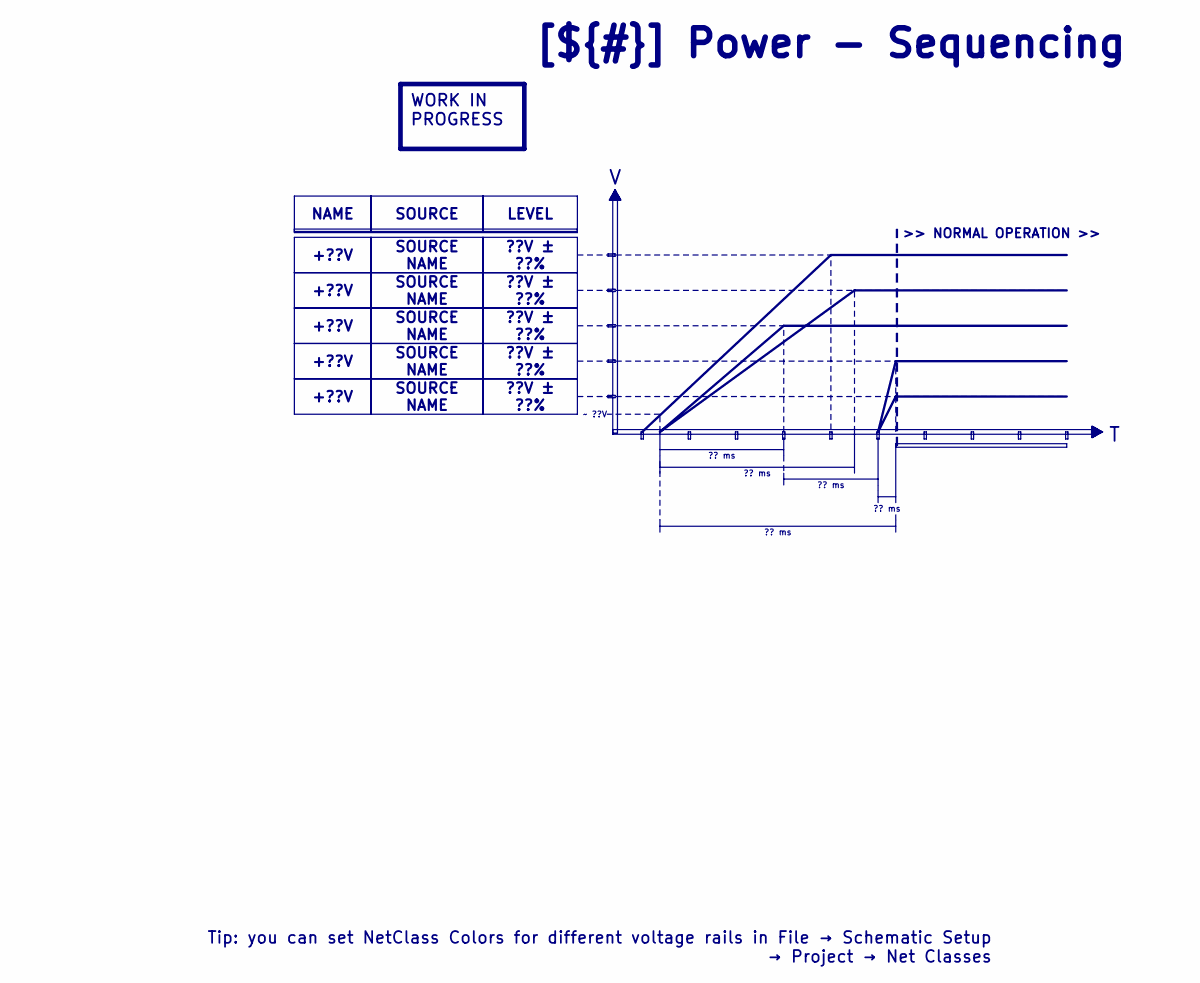
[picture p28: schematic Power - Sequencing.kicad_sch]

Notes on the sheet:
LEVEL
+??V
SOURCE NAME
?? ms
??V ± ??%
WORK IN PROGRESS
[${#}] ${TITLE}
~ ??V
NAME
SOURCE
Tip: you can set NetClass Colors for different voltage rails in File → Schematic Setup → Project → Net Classes
>> NORMAL OPERATION >>

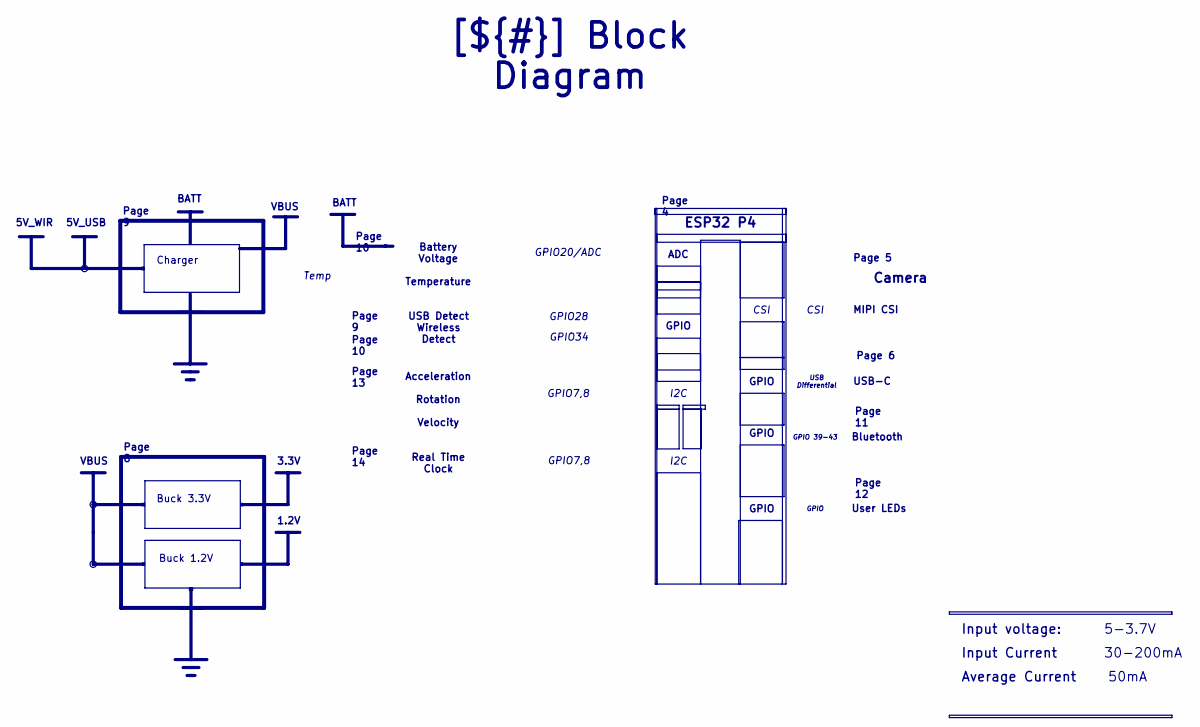
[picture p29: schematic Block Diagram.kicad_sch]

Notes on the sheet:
Charger
Bluetooth
Average Current
5V_WIR
Buck 3.3V
Input Current
Page 10
GPIO28
ESP32 P4
GPIO7,8
GPIO
Page 4
Page 14
ADC
Page 5
CSI
Page 11
Input voltage:
GPIO20/ADC
50mA
Page 12
30-200mA
Acceleration Rotation Velocity
USB Differential
Page 6
Camera
Buck 1.2V
Battery Voltage Temperature
3.3V
GPIO 39-43
VBUS
USB-C
GPIO34
Page 8
MIPI CSI
BATT
Temp
[${#}] ${TITLE}
Real Time Clock
Page 9

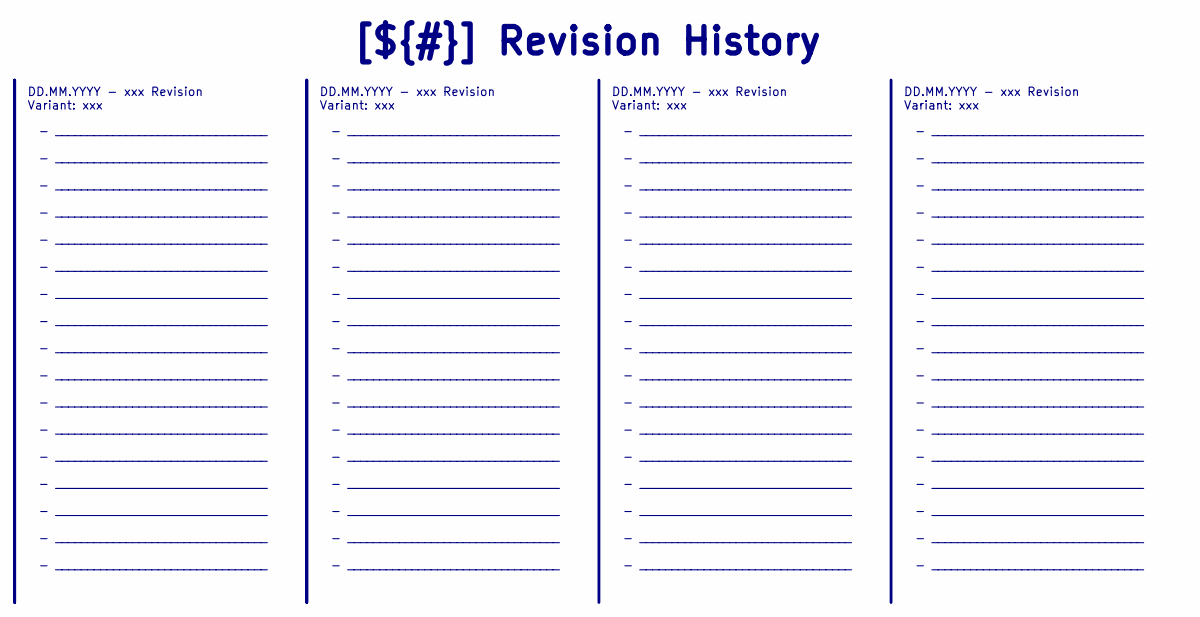
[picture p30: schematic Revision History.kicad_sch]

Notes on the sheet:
- _________________________________ - _________________________________ - _________________________________ - _________________________________ - _________________________________ - _________________________________ - _________________________________ - _________________________________ - _________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
DD.MM.YYYY - xxx Revision Variant: xxx
[${#}] ${TITLE}

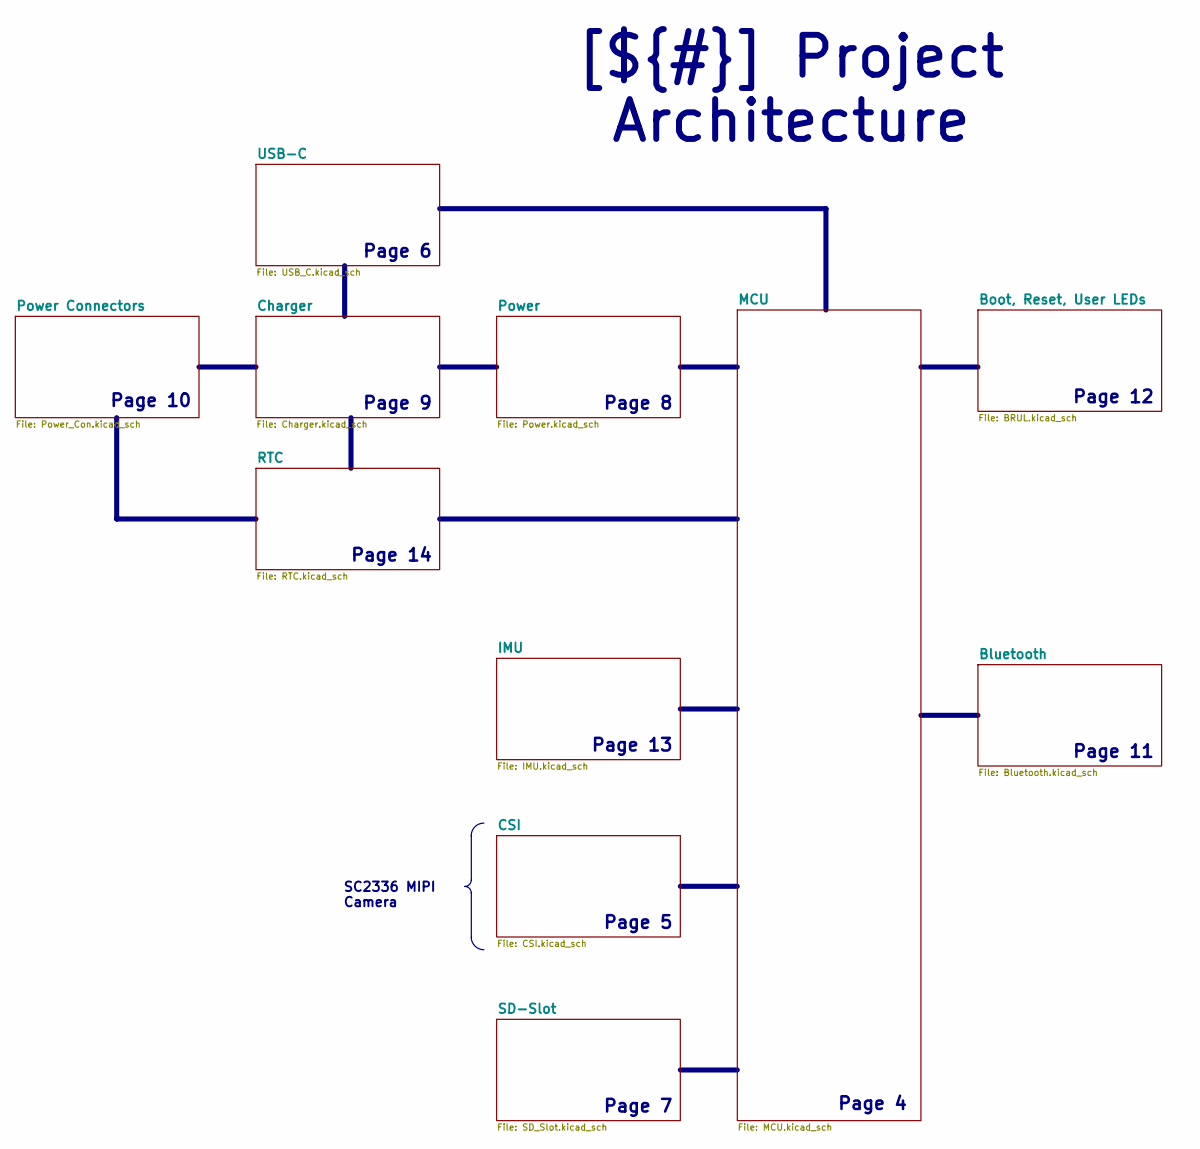
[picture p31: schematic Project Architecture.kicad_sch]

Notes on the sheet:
[${#}] ${TITLE}
SC2336 MIPI Camera
Page 13
Page 6
Page 10
Page 11
Page 14
Page 12
Page 4
Page 7
Page 5
Page 8
Page 9

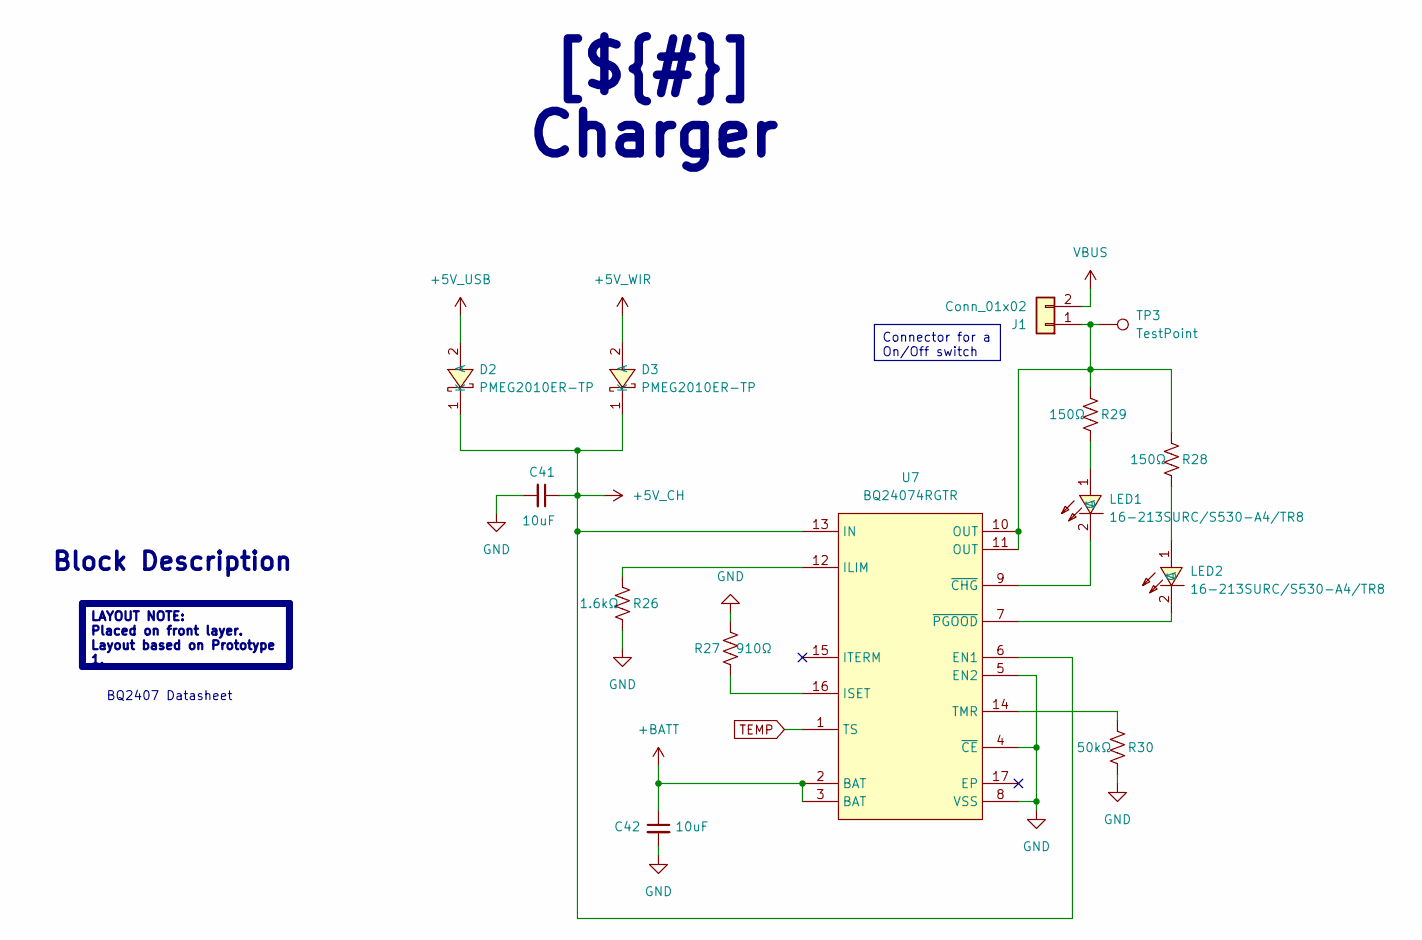
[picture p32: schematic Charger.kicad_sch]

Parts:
C41, C42: 10uF; C_0402_1005Metric
D2, D3: PMEG2010ER-TP; SOD-123F_L2.7-W1.7-LS3.6-RD; MPN PMEG2010ER-TP; LCSC Part C49231019
J1: Conn_01x02; SolderWire-0.1sqmm_1x02_P3.6mm_D0.4mm_OD1mm
LED1, LED2: 16-213SURC/S530-A4/TR8; LED0402-R-RD; MPN 16-213SURC/S530-A4/TR8; LCSC Part C74339
R26: 1.6kΩ; R_0402_1005Metric
R27: 910Ω; R_0402_1005Metric
R28, R29: 150Ω; R_0402_1005Metric
R30: 50kΩ; R_0402_1005Metric
TP3: TestPoint; TestPoint_Pad_1.0x1.0mm
U7: BQ24074RGTR; QFN-16_L3.0-W3.0-P0.50-TL-EP1.7; MPN BQ24074RGTR; LCSC Part C54313

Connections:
+5V_CH: C41.1, D2.1 (K), D3.1 (K), U7.6 (EN1), U7.13 (IN); also elsewhere on the board
+5V_USB: D2.2 (A); also elsewhere on the board
+5V_WIR: D3.2 (A); also elsewhere on the board
+BATT: C42.1, U7.2 (BAT), U7.3 (BAT); also elsewhere on the board
GND: C41.2, C42.2, R26.2, R27.2, R30.2, U7.4 (~CE), U7.5 (EN2), U7.8 (VSS); also elsewhere on the board
unnamed 41: J1.1, R28.1, R29.1, TP3.1, U7.10 (OUT), U7.11 (OUT); also elsewhere on the board
unnamed: LED1.1 (A), R29.2
unnamed 45: LED1.2 (C), U7.9 (~CHG); also elsewhere on the board
unnamed: LED2.1 (A), R28.2
unnamed 47: LED2.2 (C), U7.7 (~PGOOD); also elsewhere on the board
unnamed 61: R26.1, U7.12 (ILIM); also elsewhere on the board
unnamed 62: R27.1, U7.16 (ISET); also elsewhere on the board
unnamed 63: R30.1, U7.14 (TMR); also elsewhere on the board

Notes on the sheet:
[${#}] ${TITLE}
Connector for a On/Off switch
Block Description
LAYOUT NOTE: Placed on front layer. Layout based on Prototype 1.
BQ2407 Datasheet

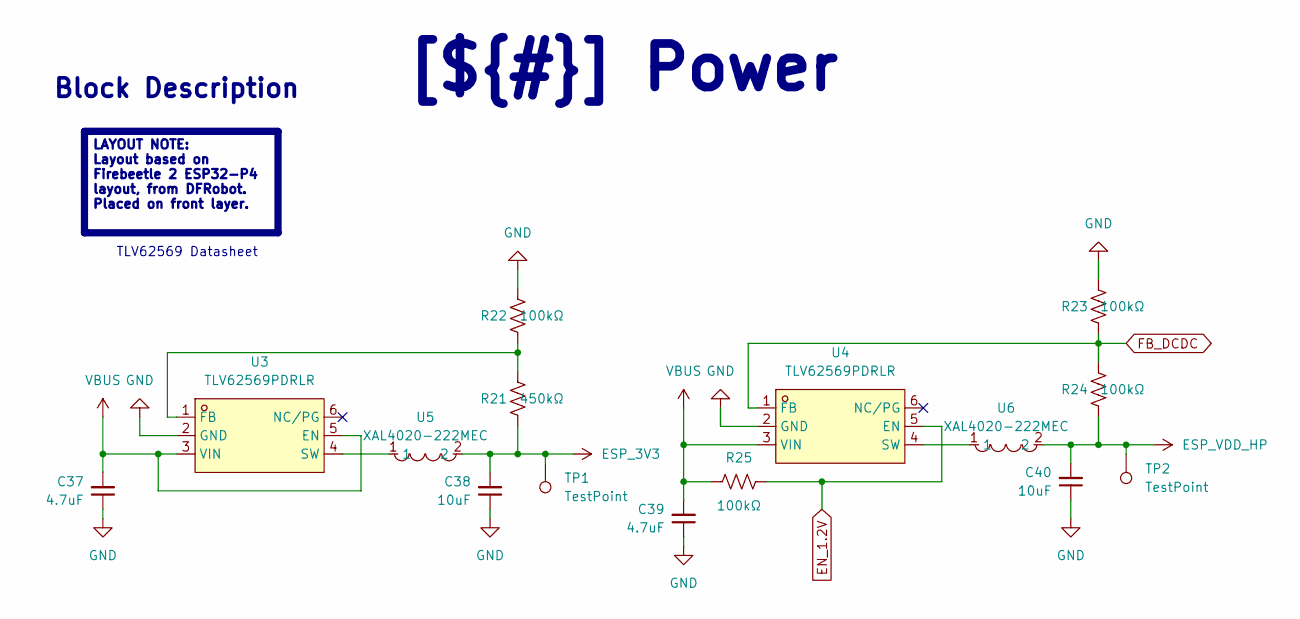
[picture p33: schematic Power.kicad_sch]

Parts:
C37, C39: 4.7uF; C_0402_1005Metric
C38, C40: 10uF; C_0402_1005Metric
R21: 450kΩ; R_0402_1005Metric
R22, R23, R24, R25: 100kΩ; R_0402_1005Metric
TP1, TP2: TestPoint; TestPoint_Pad_1.0x1.0mm
U3, U4: TLV62569PDRLR; SOT-563_L1.6-W1.2-P0.50-LS1.6-BL; MPN TLV62569PDRLR; LCSC Part C398364
U5, U6: XAL4020-222MEC; IND-SMD_L4.0-W4.0-A; MPN XAL4020-222MEC; LCSC Part C3151182

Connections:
EN_1.2V: R25.2, U4.5 (EN); also elsewhere on the board
ESP_3V3: C38.2, R21.1, TP1.1, U5.2; also elsewhere on the board
ESP_VDD_HP: C40.2, R24.1, TP2.1, U6.2; also elsewhere on the board
FB_DCDC: R23.1, R24.2, U4.1 (FB); also elsewhere on the board
GND: C37.1, C38.1, C39.1, C40.1, R22.2, R23.2, U3.2 (GND), U4.2 (GND); also elsewhere on the board
unnamed 58: R21.2, R22.1, U3.1 (FB); also elsewhere on the board
unnamed 59: U3.4 (SW), U5.1; also elsewhere on the board
unnamed 60: U4.4 (SW), U6.1; also elsewhere on the board
VBUS: C37.2, C39.2, R25.1, U3.3 (VIN), U3.5 (EN), U4.3 (VIN); also elsewhere on the board

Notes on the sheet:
[${#}] ${TITLE}
Block Description
LAYOUT NOTE: Layout based on Firebeetle 2 ESP32-P4 layout, from DFRobot. Placed on front layer.
TLV62569 Datasheet

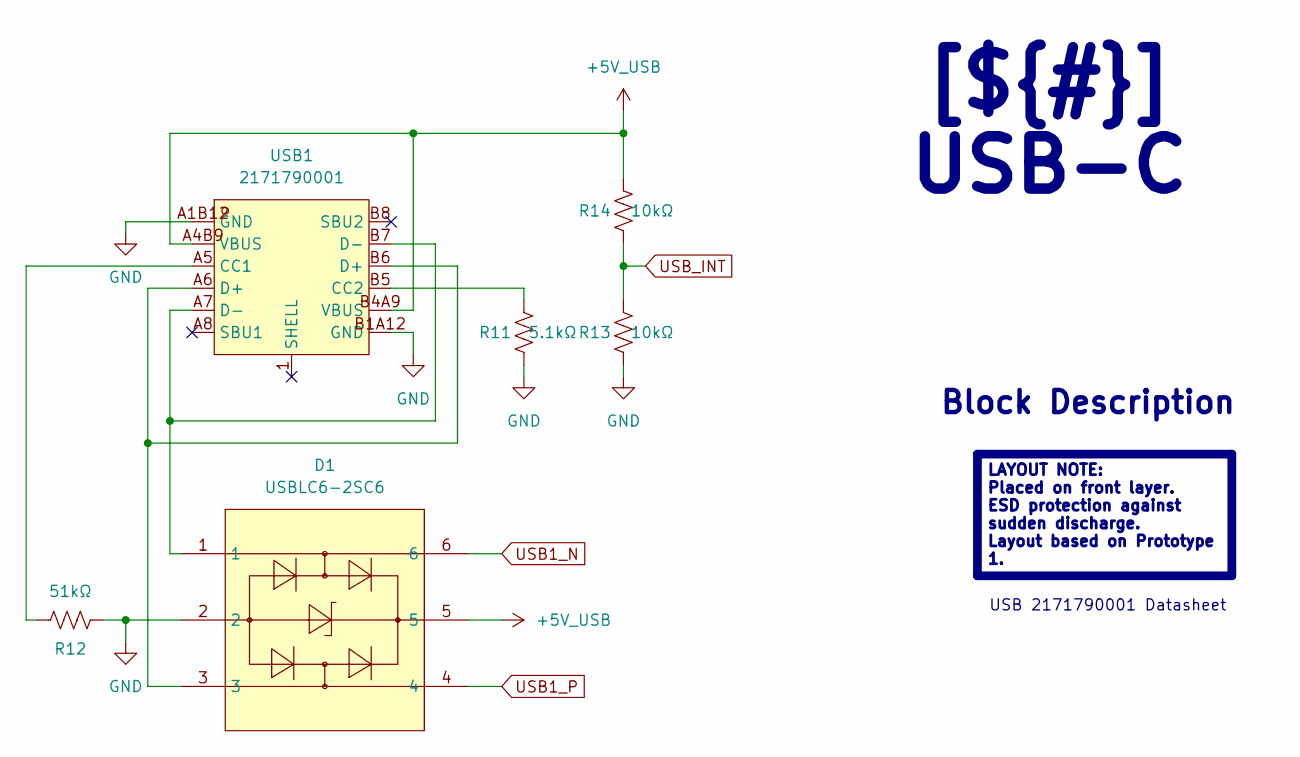
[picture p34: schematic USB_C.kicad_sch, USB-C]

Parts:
D1: USBLC6-2SC6; SOT-23-6_L2.9-W1.6-P0.95-LS2.8-BL; MPN USBLC6-2SC6; LCSC Part C7519
R11: 5.1kΩ; R_0402_1005Metric
R12: 51kΩ; R_0402_1005Metric
R13, R14: 10kΩ; R_0402_1005Metric
USB1: 2171790001; USB-C-SMD_2171790001; MPN 2171790001; LCSC Part C3197684

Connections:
+5V_USB: D1.5, R14.2, USB1.A4B9 (VBUS), USB1.B4A9 (VBUS); also elsewhere on the board
GND: D1.2, R11.1, R12.1, R13.1, USB1.A1B12 (GND), USB1.B1A12 (GND); also elsewhere on the board
unnamed: D1.1, USB1.A7 (D-), USB1.B7 (D-)
unnamed: D1.3, USB1.A6 (D+), USB1.B6 (D+)
unnamed: R12.2, USB1.A5 (CC1)
unnamed: R11.2, USB1.B5 (CC2)
USB1_N: D1.6; also elsewhere on the board
USB1_P: D1.4; also elsewhere on the board
USB_INT: R13.2, R14.1; also elsewhere on the board

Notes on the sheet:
Block Description
[${#}] ${TITLE}
LAYOUT NOTE: Placed on front layer. ESD protection against sudden discharge. Layout based on Prototype 1.
USB 2171790001 Datasheet

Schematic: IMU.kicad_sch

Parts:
C46, C47: 100nF; C_0402_1005Metric
R41, R42: 10kΩ; R_0402_1005Metric
U11: LSM6DSOTR; LGA-14_L3.0-W2.5-P0.50-TL; MPN LSM6DSOTR; LCSC Part C2655100

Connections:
ESP_3V3: C46.1, C47.2, R41.2, U11.5 (VDDIO), U11.8 (VDD); also elsewhere on the board
GND: C46.2, C47.1, R42.1, U11.6 (GND), U11.7 (GND); also elsewhere on the board
unnamed 64: R41.1, U11.12 (CS); also elsewhere on the board
unnamed 65: R42.2, U11.1 (SDO/SA0), U11.2 (SDX), U11.3 (SCX); also elsewhere on the board

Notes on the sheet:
Block Description
LAYOUT NOTE: Placed on front layer. Layout based on Prototype 1.
[${#}] ${TITLE}
LSM6DSOTR Datasheet

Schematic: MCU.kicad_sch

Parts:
C1, C4: 10uF; C_0402_1005Metric
C2, C3, C5, C7, C9, C12, C14, C16, C21, C23, C24, C25, C27, C28, C31, C32, C33, C34: 100nF; C_0402_1005Metric
C6, C10, C13, C15, C17, C18, C19, C20, C22, C26: 1uF; C_0402_1005Metric
C8, C11: 10nF; C_0402_1005Metric
C29, C30: 18pF; C_0402_1005Metric
H1, H2, H3: MountingHole; MountingHole_3.2mm_M3
R1, R4, R5: 10kΩ; R_0402_1005Metric
R2, R3: 4.02kΩ; R_0402_1005Metric
U1: ESP32-P4NRW32X; QFN-104_L10.0-W10.0-P0.35-TL-EP7.5; MPN ESP32-P4NRW32X; LCSC Part C54540373
U2: W25Q128JVSIQ; SOIC127P790X216-8N; PARTREV I
Y1: Crystal_GND24_Small; Crystal_SMD_3225-4Pin_3.2x2.5mm

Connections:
BATT_MEASURE_USB: U1.22 (GPIO20); also elsewhere on the board
BOOT: U1.66 (GPIO35); also elsewhere on the board
C6_EN: U1.10 (GPIO9); also elsewhere on the board
C6_WAKEUP: U1.6 (GPIO6); also elsewhere on the board
CSI_CLK_N: U1.45 (CSI_CLKN); also elsewhere on the board
CSI_CLK_P: U1.44 (CSI_CLKP); also elsewhere on the board
CSI_D0_N: U1.42 (CSI_DATAN0); also elsewhere on the board
CSI_D0_P: U1.43 (CSI_DATAP0); also elsewhere on the board
CSI_D1_N: U1.46 (CSI_DATAN1); also elsewhere on the board
CSI_D1_P: U1.47 (CSI_DATAP1); also elsewhere on the board
CSI_PWR: U1.25 (GPIO23); also elsewhere on the board
DETECT_WIR: U1.65 (GPIO34); also elsewhere on the board
EN_1.2V: U1.79 (EN_DCDC); also elsewhere on the board
ESP_3V3: C1.1, C2.1, C3.1, C11.1, C12.1, C13.1, C16.2, C21.2, C22.1, C24.2, C28.2, C31.1, C32.1, R4.2, R5.2, U1.9 (VDD_LP), U1.21 (VDD_IO_0), U1.51 (VDD_USBPHY), U1.62 (VDD_IO_4), U1.75 (VDD_LDO), U1.77 (VDD_DCDCC), U1.96 (VDD_IO_6), U1.101 (VDD_ANA), U1.102 (VDD_BAT); also elsewhere on the board
ESP_LDO_VO1: C6.2, C7.2, C20.2, C34.1, R1.1, U1.30 (VDD_FLASHIO), U1.71 (VDDO_FLASH), U2.8 (VCC); also elsewhere on the board
ESP_LDO_VO2: C14.1, C15.2, C19.2, U1.59 (VDD_PSRAM_0), U1.67 (VDD_PSRAM_1), U1.72 (VDDO_PSRAM)
ESP_LDO_VO3: C8.1, C9.1, C10.1, C18.2, U1.41 (VDD_MIPI_DPHY), U1.73 (VDDO_3)
ESP_LDO_VO4: C17.2, C25.1, C26.2, U1.74 (VDDO_4), U1.85 (VDD_IO_5); also elsewhere on the board
ESP_SCL: U1.8 (GPIO8); also elsewhere on the board
ESP_SDA: U1.7 (GPIO7); also elsewhere on the board
ESP_VDD_HP: C4.1, C5.1, C23.2, C27.2, U1.26 (VDD_HP_0), U1.76 (VDD_HP_2), U1.91 (VDD_HP_3); also elsewhere on the board
FB_DCDC: U1.78 (FB_DCDC); also elsewhere on the board
FLASH_CK: U1.32 (FLASH_CK), U2.6 (CLK); also elsewhere on the board
FLASH_CS: R1.2, U1.27 (FLASH_CS), U2.1 (/CS); also elsewhere on the board
FLASH_D: U1.33 (FLASH_D), U2.5 (DI(IO0)); also elsewhere on the board
FLASH_HOLD: U1.31 (FLASH_HOLD), U2.7 (/HOLD/RESET(IO3)); also elsewhere on the board
FLASH_Q: U1.28 (FLASH_Q), U2.2 (DO(IO1)); also elsewhere on the board
FLASH_WP: U1.29 (FLASH_WP), U2.3 (/WP(IO2)); also elsewhere on the board
GND: C1.2, C2.2, C3.2, C4.2, C5.2, C6.1, C7.1, C8.2, C9.2, C10.2, C11.2, C12.2, C13.2, C14.2, C15.1, C16.1, C17.1, C18.1, C19.1, C20.1, C21.1, C22.2, C23.1, C24.1, C25.2, C26.1, C27.1, C28.1, C29.2, C30.2, C31.2, C32.2, C33.2, C34.2, R2.1, R3.1, U1.105 (GND), U2.4 (GND), Y1.2, Y1.4; also elsewhere on the board
unnamed: R3.2, U1.48 (CSI_REXT)
unnamed: R2.2, U1.34 (DSI_REXT)
unnamed: R4.1, U1.68 (GPIO36)
unnamed: C29.1, U1.99 (XTAL_N), Y1.3
unnamed: C30.1, U1.100 (XTAL_P), Y1.1
RESET: C33.1, R5.1, U1.103 (CHIP_PU); also elsewhere on the board
RTC_INT: U1.55 (GPIO26); also elsewhere on the board
SD1_CLK: U1.84 (GPIO43); also elsewhere on the board
SD1_CMD: U1.86 (GPIO44); also elsewhere on the board
SD1_D0: U1.80 (GPIO39); also elsewhere on the board
SD1_D1: U1.81 (GPIO40); also elsewhere on the board
SD1_D2: U1.82 (GPIO41); also elsewhere on the board
SD1_D3: U1.83 (GPIO42); also elsewhere on the board
SD1_PWRN: U1.3 (GPIO3); also elsewhere on the board
SDIO_CLK: U1.19 (GPIO18); also elsewhere on the board
SDIO_CMD: U1.20 (GPIO19); also elsewhere on the board
SDIO_D0: U1.15 (GPIO14); also elsewhere on the board
SDIO_D1: U1.16 (GPIO15); also elsewhere on the board
SDIO_D2: U1.17 (GPIO16); also elsewhere on the board
SDIO_D3: U1.18 (GPIO17); also elsewhere on the board
USB1_N: U1.52 (GPIO24); also elsewhere on the board
USB1_P: U1.53 (GPIO25); also elsewhere on the board
USB_INT: U1.57 (GPIO28); also elsewhere on the board
USER_LED_1: U1.1 (GPIO1); also elsewhere on the board
USER_LED_2: U1.2 (GPIO2); also elsewhere on the board

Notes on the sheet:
LAYOUT NOTE: Layout based on Firebeetle 2 ESP32-P4 layout, from DFRobot. Placed on front layer.
[${#}] ${TITLE}
Block Description
DESIGN NOTE: 40MHz, +-10ppm
Serial Flash Memory
W25Q128JVSIQ Datasheet
ESP32-P4 Datasheet

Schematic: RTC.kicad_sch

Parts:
C48: 1uF; C_0402_1005Metric
R43, R44, R45: 3.3kΩ; R_0402_1005Metric
U12: DS3231MZ+_C722467; SOIC-8_L4.9-W3.9-P1.27-LS6.0-BL; MPN DS3231MZ+; LCSC Part C722467

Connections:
+BATT2: C48.1, U12.6 (VBAT); also elsewhere on the board
ESP_3V3: R43.2, R44.2, R45.2; also elsewhere on the board
ESP_SCL: R43.1, U12.8 (SCL); also elsewhere on the board
ESP_SDA: R44.1, U12.7 (SDA); also elsewhere on the board
GND: C48.2, U12.5 (GND); also elsewhere on the board
RTC_INT: R45.1, U12.3 (~INT/SQW); also elsewhere on the board

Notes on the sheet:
Block Description
LAYOUT NOTE: Placed on back layer. Layout based on Prototype 1.
[${#}] ${TITLE}
DS3231MZ+ Datasheet

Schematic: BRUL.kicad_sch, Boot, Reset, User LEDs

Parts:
LED3, LED4, LED5: 16-213SURC/S530-A4/TR8; LED0402-R-RD; MPN 16-213SURC/S530-A4/TR8; LCSC Part C74339
R37: 330Ω; R_0402_1005Metric
R38, R39: 2.2kΩ; R_0402_1005Metric
R40: 4.7kΩ; R_0402_1005Metric
SW1, SW2: 1TS026A-1000-0550-CT; SW-SMD_4P-L2.6-W1.6-P0.75-LS3.0; MPN 1TS026A-1000-0550-CT; LCSC Part C913778

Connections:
BOOT: R40.1, SW2.3, SW2.4; also elsewhere on the board
ESP_3V3: R37.1, R40.2; also elsewhere on the board
GND: LED3.2 (C), LED4.2 (C), LED5.2 (C), SW1.1, SW1.2, SW2.1, SW2.2; also elsewhere on the board
unnamed: LED3.1 (A), R37.2
unnamed: LED4.1 (A), R38.2
unnamed: LED5.1 (A), R39.2
RESET: SW1.3, SW1.4; also elsewhere on the board
USER_LED_1: R38.1; also elsewhere on the board
USER_LED_2: R39.1; also elsewhere on the board

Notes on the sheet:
Block Description
LAYOUT NOTE: Layout based on Firebeetle 2 ESP32-P4 layout, from DFRobot. Placed on front layer.
TBD what to use them for
[${#}] ${TITLE}

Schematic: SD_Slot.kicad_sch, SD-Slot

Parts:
C49: 1uF; C_0402_1005Metric
C50: 100nF; C_0402_1005Metric
Q2: AO3401A_C306862; SOT-23-3_L2.9-W1.3-P1.90-LS2.4-BR; MPN AO3401A; LCSC Part C306862
R15: 51kΩ; R_0402_1005Metric
R16, R17, R18, R19, R20: 10kΩ; R_0402_1005Metric
SD1: 503398-1892; TF-SMD_503398-1892; MPN 5033981892; LCSC Part C428492

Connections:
ESP_3V3: Q2.2 (S); also elsewhere on the board
ESP_LDO_VO4: R16.1, R17.1, R18.1, R19.1, R20.1; also elsewhere on the board
GND: C49.1, C50.1, R15.2, SD1.6 (VSS); also elsewhere on the board
unnamed 52: C49.2, C50.2, Q2.3 (D), SD1.4 (VDD); also elsewhere on the board
SD1_CMD: R18.2, SD1.3 (CMD); also elsewhere on the board
SD1_D0: R19.2, SD1.7 (DAT0); also elsewhere on the board
SD1_D1: R20.2, SD1.8 (DAT1); also elsewhere on the board
SD1_D2: R16.2, SD1.1 (DAT2); also elsewhere on the board
SD1_D3: R17.2, SD1.2 (CD/DAT3); also elsewhere on the board
SD1_PWRN: Q2.1 (G), R15.1; also elsewhere on the board

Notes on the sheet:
[${#}] ${TITLE}
Block Description
LAYOUT NOTE: Layout based on Firebeetle 2 ESP32-P4 layout, from DFRobot. Placed on front layer.
Molex 503398-1892 Datasheet

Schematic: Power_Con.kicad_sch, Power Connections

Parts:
BAT1: 3000; BAT-SMD_CR1202; MPN 3000; LCSC Part C238097
JP1: SolderJumper_3_Bridged12; SolderJumper-3_P1.3mm_Bridged2Bar12_RoundedPad1.0x1.5mm
R31: 750Ω; R_0402_1005Metric
R32, R34: 10kΩ; R_0402_1005Metric
R33: 24.9kΩ; R_0402_1005Metric
R35: 15kΩ; R_0402_1005Metric
U8: SM03B-SRSS-TB; CONN-SMD_SM03B-SRSS-TB-LF-SN-P; MPN SM03B-SRSS-TB(LF)(SN); LCSC Part C160403
U9: S2B-PH-K-S; CONN-TH_S2B-PH-K-S-LF-SN; MPN S2B-PH-K-S(LF)(SN); LCSC Part C173752

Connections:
+5V_WIR: R34.2, U9.2; also elsewhere on the board
+BATT: R32.2, U8.1; also elsewhere on the board
BATT_MEASURE_USB: R32.1, R33.2; also elsewhere on the board
DETECT_WIR: R34.1, R35.2; also elsewhere on the board
GND: BAT1.3 (-), R31.1, R33.1, R35.1, U8.2, U9.1; also elsewhere on the board
unnamed: BAT1.1 (+), BAT1.2 (+)
unnamed 42: JP1.1 (A), U8.3; also elsewhere on the board
unnamed: JP1.3 (B), R31.2
TEMP: JP1.2 (C); also elsewhere on the board

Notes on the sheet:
LAYOUT NOTE: Placed on back layer. Layout based on Prototype 1.
Block Description
DFR0362
[${#}] ${TITLE}
RTC Battery Connector
Wireless Charger Connector
Battery Connector

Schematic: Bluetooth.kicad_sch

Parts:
C43, C45: 100nF; C_0402_1005Metric
C44: 10nF; C_0402_1005Metric
R36: 10kΩ; R_0402_1005Metric
U10: ESP32-C6-MINI-1-N4; WIFIM-SMD_61P-L16.6-W13.2-P0.80-ESP32-C6-MINI-1-N4; MPN ESP32-C6-MINI-1-N4; LCSC Part C5736265

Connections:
C6_EN: C45.1, R36.2, U10.8 (EN); also elsewhere on the board
ESP_3V3: C43.2, C44.2, R36.1, U10.3 (3V3); also elsewhere on the board
GND: C43.1, C44.1, C45.2, U10.1 (GND), U10.2 (GND), U10.11 (GND), U10.14 (GND), U10.36 (GND), U10.37 (GND), U10.38 (GND), U10.39 (GND), U10.40 (GND), U10.41 (GND), U10.42 (GND), U10.43 (GND), U10.44 (GND), U10.45 (GND), U10.46 (GND), U10.47 (GND), U10.48 (GND), U10.49 (GND), U10.50 (GND), U10.51 (GND), U10.52 (GND), U10.53 (GND); also elsewhere on the board

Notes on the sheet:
Block Description
LAYOUT NOTE: Layout based on Firebeetle 2 ESP32-P4 layout, from DFRobot. Placed on front layer.
[${#}] ${TITLE}
ESP32-C6-MINI-1 Datasheet

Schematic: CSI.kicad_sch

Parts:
C35: 100nF; C_0402_1005Metric
C36: 10nF; C_0402_1005Metric
FPC1: 1.0-15P下接; FPC-SMD_C66660; MPN 1.0-15P下接; LCSC Part C66660
Q1: AO3401A_C306862; SOT-23-3_L2.9-W1.3-P1.90-LS2.4-BR; MPN AO3401A; LCSC Part C306862
R6: 51kΩ; R_0402_1005Metric
R7, R8: 2.2kΩ; R_0402_1005Metric
R9, R10: 10kΩ; R_0402_1005Metric

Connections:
CSI_PWR: Q1.1 (G), R6.1; also elsewhere on the board
ESP_3V3: Q1.2 (S); also elsewhere on the board
GND: C35.1, C36.1, FPC1.1, FPC1.4, FPC1.7, FPC1.10, R6.2; also elsewhere on the board
unnamed 37: FPC1.11, R10.2; also elsewhere on the board
unnamed 38: FPC1.12, R9.2; also elsewhere on the board
unnamed 39: FPC1.13, R8.2; also elsewhere on the board
unnamed 40: FPC1.14, R7.2; also elsewhere on the board
unnamed 51: C35.2, C36.2, FPC1.15, Q1.3 (D), R7.1, R8.1, R9.1, R10.1; also elsewhere on the board

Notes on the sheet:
[${#}] ${TITLE}
Block Description
LAYOUT NOTE: Layout based on Firebeetle 2 ESP32-P4 layout, from DFRobot. Placed on front layer.

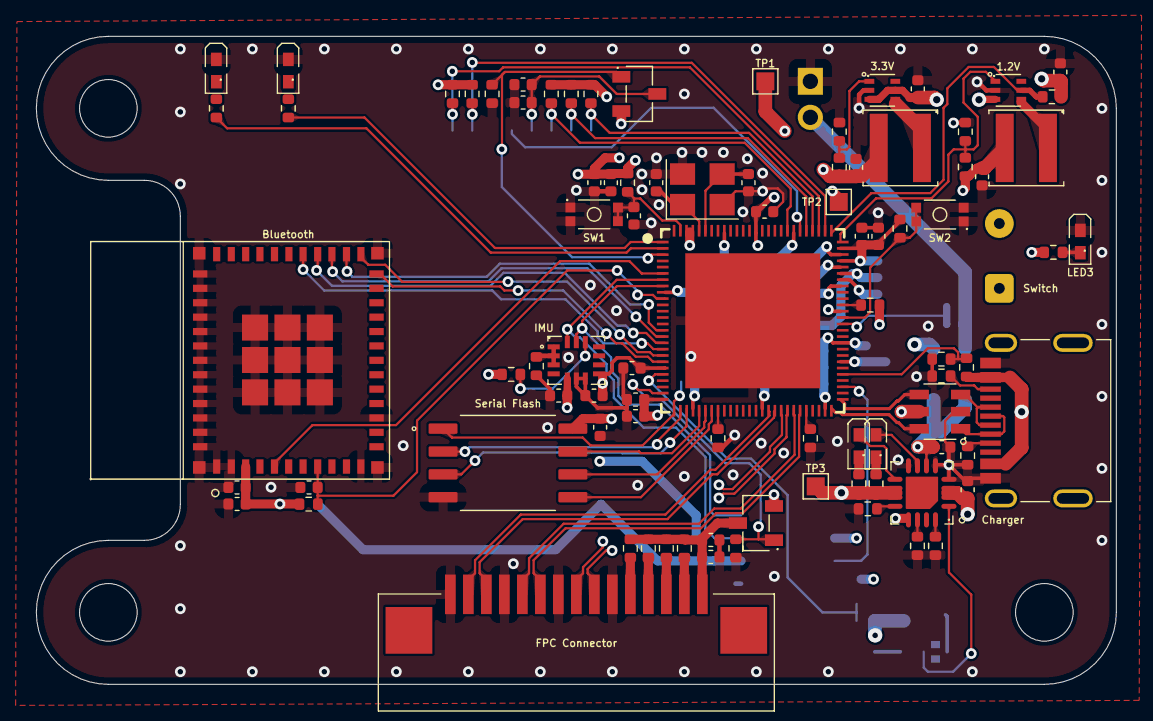
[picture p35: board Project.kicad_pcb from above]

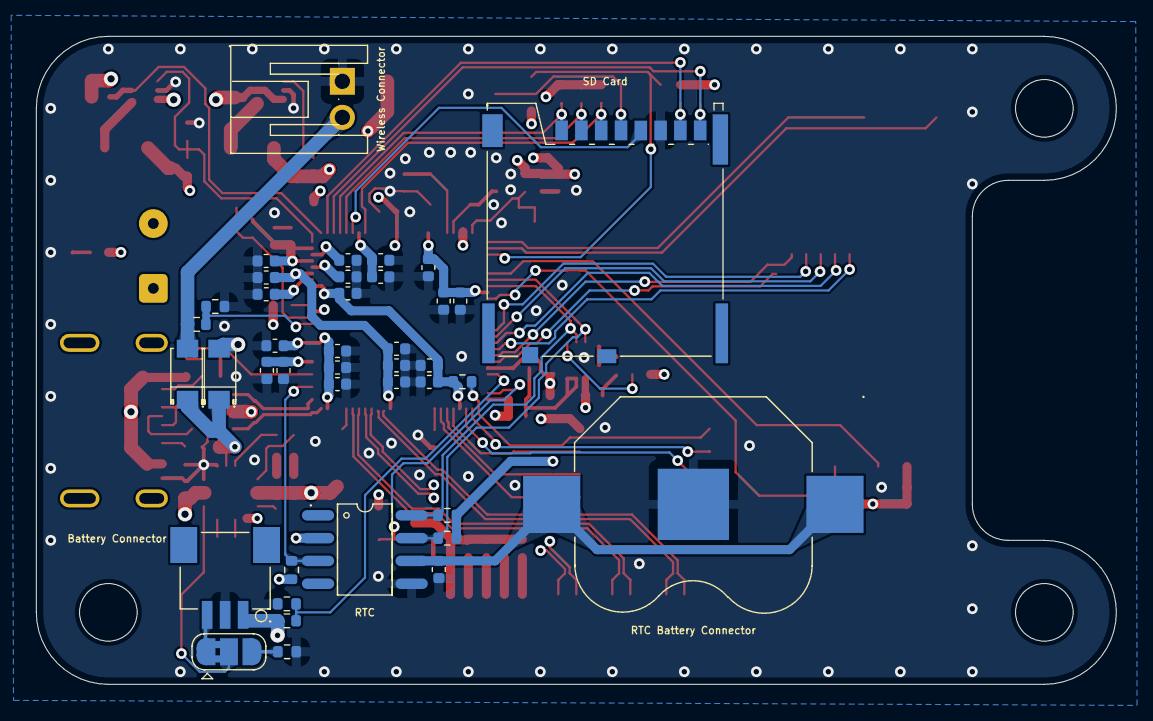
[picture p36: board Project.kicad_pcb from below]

Board: 4 copper layers, 60.0 x 36.0 mm, 132 parts (40 on the bottom side), 89 nets.

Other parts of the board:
1.2V, 3.3V: TLV62569PDRLR; SOT-563_L1.6-W1.2-P0.50-LS1.6-BL
Battery Connector: SM03B-SRSS-TB; CONN-SMD_SM03B-SRSS-TB-LF-SN-P
Bluetooth: ESP32-C6-MINI-1-N4; WIFIM-SMD_61P-L16.6-W13.2-P0.80-ESP32-C6-MINI-1-N4
Charger: BQ24074RGTR; QFN-16_L3.0-W3.0-P0.50-TL-EP1.7
FPC Connector: 1.0-15P下接; FPC-SMD_C66660
IMU: LSM6DSOTR; LGA-14_L3.0-W2.5-P0.50-TL
RTC: DS3231MZ+_C722467; SOIC-8_L4.9-W3.9-P1.27-LS6.0-BL
RTC Battery Connector: 3000; BAT-SMD_CR1202
SD Card: 503398-1892; TF-SMD_503398-1892
Serial Flash: W25Q128JVSIQ; SOIC127P790X216-8N
Switch: Conn_01x02; SolderWire-0.1sqmm_1x02_P3.6mm_D0.4mm_OD1mm
Wireless Connector: S2B-PH-K-S; CONN-TH_S2B-PH-K-S-LF-SN

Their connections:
+5V_CH: Charger.6 (EN1), Charger.13 (IN), RTC.2 (VCC); also elsewhere on the board
+5V_WIR: Wireless Connector.2; also elsewhere on the board
+BATT: Battery Connector.1, Charger.2 (BAT), Charger.3 (BAT); also elsewhere on the board
+BATT2: RTC.6 (VBAT), RTC Battery Connector.1 (+), RTC Battery Connector.2 (+); also elsewhere on the board
C6_EN: Bluetooth.8 (EN); also elsewhere on the board
C6_WAKEUP: Bluetooth.5 (IO2); also elsewhere on the board
CSI_CLK_N: FPC Connector.9; also elsewhere on the board
CSI_CLK_P: FPC Connector.8; also elsewhere on the board
CSI_D0_N: FPC Connector.2; also elsewhere on the board
CSI_D0_P: FPC Connector.3; also elsewhere on the board
CSI_D1_N: FPC Connector.5; also elsewhere on the board
CSI_D1_P: FPC Connector.6; also elsewhere on the board
EN_1.2V: 1.2V.5 (EN); also elsewhere on the board
ESP_3V3: Bluetooth.3 (3V3), IMU.5 (VDDIO), IMU.8 (VDD); also elsewhere on the board
ESP_LDO_VO1: Serial Flash.8 (VCC); also elsewhere on the board
ESP_SCL: IMU.13 (SCL), RTC.8 (SCL); also elsewhere on the board
ESP_SDA: IMU.14 (SDA), RTC.7 (SDA); also elsewhere on the board
FB_DCDC: 1.2V.1 (FB); also elsewhere on the board
FLASH_CK: Serial Flash.6 (CLK); also elsewhere on the board
FLASH_CS: Serial Flash.1 (/CS); also elsewhere on the board
FLASH_D: Serial Flash.5 (DI(IO0)); also elsewhere on the board
FLASH_HOLD: Serial Flash.7 (/HOLD/RESET(IO3)); also elsewhere on the board
FLASH_Q: Serial Flash.2 (DO(IO1)); also elsewhere on the board
FLASH_WP: Serial Flash.3 (/WP(IO2)); also elsewhere on the board
GND: 1.2V.2 (GND), 3.3V.2 (GND), Battery Connector.2, Bluetooth.1 (GND), Bluetooth.2 (GND), Bluetooth.11 (GND), Bluetooth.14 (GND), Bluetooth.36 (GND), Bluetooth.37 (GND), Bluetooth.38 (GND), Bluetooth.39 (GND), Bluetooth.40 (GND), Bluetooth.41 (GND), Bluetooth.42 (GND), Bluetooth.43 (GND), Bluetooth.44 (GND), Bluetooth.45 (GND), Bluetooth.46 (GND), Bluetooth.47 (GND), Bluetooth.48 (GND), Bluetooth.49 (GND), Bluetooth.50 (GND), Bluetooth.51 (GND), Bluetooth.52 (GND), Bluetooth.53 (GND), Charger.4 (~CE), Charger.5 (EN2), Charger.8 (VSS), FPC Connector.1, FPC Connector.4, FPC Connector.7, FPC Connector.10, IMU.6 (GND), IMU.7 (GND), RTC.5 (GND), RTC Battery Connector.3 (-), SD Card.6 (VSS), Serial Flash.4 (GND), Wireless Connector.1; also elsewhere on the board
unnamed 37: FPC Connector.11; also elsewhere on the board
unnamed 38: FPC Connector.12; also elsewhere on the board
unnamed 39: FPC Connector.13; also elsewhere on the board
unnamed 40: FPC Connector.14; also elsewhere on the board
unnamed 41: Charger.10 (OUT), Charger.11 (OUT), Switch.1; also elsewhere on the board
unnamed 42: Battery Connector.3; also elsewhere on the board
unnamed 45: Charger.9 (~CHG); also elsewhere on the board
unnamed 47: Charger.7 (~PGOOD); also elsewhere on the board
unnamed 51: FPC Connector.15; also elsewhere on the board
unnamed 52: SD Card.4 (VDD); also elsewhere on the board
unnamed 58: 3.3V.1 (FB); also elsewhere on the board
unnamed 59: 3.3V.4 (SW); also elsewhere on the board
unnamed 60: 1.2V.4 (SW); also elsewhere on the board
unnamed 61: Charger.12 (ILIM); also elsewhere on the board
unnamed 62: Charger.16 (ISET); also elsewhere on the board
unnamed 63: Charger.14 (TMR); also elsewhere on the board
unnamed 64: IMU.12 (CS); also elsewhere on the board
unnamed 65: IMU.1 (SDO/SA0), IMU.2 (SDX), IMU.3 (SCX); also elsewhere on the board
RTC_INT: RTC.3 (~INT/SQW); also elsewhere on the board
SD1_CLK: SD Card.5 (CLK); also elsewhere on the board
SD1_CMD: SD Card.3 (CMD); also elsewhere on the board
SD1_D0: SD Card.7 (DAT0); also elsewhere on the board
SD1_D1: SD Card.8 (DAT1); also elsewhere on the board
SD1_D2: SD Card.1 (DAT2); also elsewhere on the board
SD1_D3: SD Card.2 (CD/DAT3); also elsewhere on the board
SDIO_CLK: Bluetooth.25 (IO19); also elsewhere on the board
SDIO_CMD: Bluetooth.24 (IO18); also elsewhere on the board
SDIO_D0: Bluetooth.26 (IO20); also elsewhere on the board
SDIO_D1: Bluetooth.27 (IO21); also elsewhere on the board
SDIO_D2: Bluetooth.28 (IO22); also elsewhere on the board
SDIO_D3: Bluetooth.29 (IO23); also elsewhere on the board
TEMP: Charger.1 (TS); also elsewhere on the board
VBUS: 1.2V.3 (VIN), 3.3V.3 (VIN), 3.3V.5 (EN), Switch.2; also elsewhere on the board

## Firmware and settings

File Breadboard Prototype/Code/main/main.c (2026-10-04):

/* Firmware composition root: boot policy, commands, tasks, and power lifecycle. */

#include <ctype.h>
#include <errno.h>
#include <inttypes.h>
#include <stdio.h>
#include <stdlib.h>
#include <string.h>
#include <strings.h>
#include <time.h>

#include "driver/gpio.h"
#include "driver/uart.h"
#include "driver/usb_serial_jtag.h"
#include "esp_attr.h"
#include "esp_check.h"
#include "esp_err.h"
#include "esp_idf_version.h"
#include "esp_log.h"
#include "esp_vfs_fat.h"
#include "nvs_flash.h"
#include "nvs.h"
#include "esp_system.h"
#include "esp_sleep.h"
#include "esp_rtc_time.h"
#include "esp_timer.h"
#include "esp_task_wdt.h"
#include "esp_core_dump.h"
#include "freertos/FreeRTOS.h"
#include "freertos/semphr.h"
#include "freertos/task.h"

#if CONFIG_BT_ENABLED
#include "host/ble_hs.h"
#include "host/ble_store.h"
#include "host/ble_uuid.h"
#include "host/util/util.h"
#include "nimble/nimble_port.h"
#include "nimble/nimble_port_freertos.h"
#include "os/os_mbuf.h"
#include "services/gap/ble_svc_gap.h"
#include "services/gatt/ble_svc_gatt.h"
#endif

#include "camera.h"
#include "app_controller.h"
#include "capture_scheduler.h"
#include "daily_summary.h"
#include "device_credentials.h"
#include "health_diag.h"
#include "image_crypto.h"
#include "log_sink.h"
#include "media_transfer.h"
#include "program_state.h"
#include "program_persistence.h"
#include "protocol_version.h"
#include "rtc.h"
#include "sd_storage.h"
#include "watchdog_supervisor.h"
#include "event_breadcrumbs.h"
#include "communications_policy.h"
#include "communications_control.h"
#include "command_transport.h"
#include "command_dispatcher.h"
#include "media_commands.h"
#include "startup_init.h"
#include "diagnostic_commands.h"
#include "summary_commands.h"
#include "usb_msc.h"

/*
 * Application coordinator.
 *
 * Responsibilities are intentionally split by subsystem:
 * - RTC + soft clock: provide timestamps even if a transient RTC read fails.
 * - Serial command task: line-oriented control/data protocol for the Python GUI.
 * - Camera scheduler: button-controlled periodic capture and deep-sleep timing.
 * - Storage/logging: encrypted timestamp log and encrypted image transfer.
 *
 * The global flags below are small cross-task state signals. They are kept
 * simple because the system has only a few coarse modes: capture, transfer,
 * paused, and sleep-prep. Longer critical sections use explicit mutexes.
 */

static const char *TAG = "rtc_sd_app";
static SemaphoreHandle_t s_rtc_mutex = NULL;
static rtc_t *s_camera_rtc = NULL;
static imu_orientation_t *s_camera_imu = NULL;
static bool s_skip_initial_idle_once = false;
static bool s_resume_from_timer_wakeup = false;
static bool s_soft_clock_valid = false;
static time_t s_soft_clock_base_epoch = 0;
static int64_t s_soft_clock_base_us = 0;

/* RTC_DATA_ATTR survives deep sleep, which is the normal transition between
 * autonomous captures. The magic values distinguish retained state from a
 * cold boot; NVS is consulted only when retained state is unavailable. */
RTC_DATA_ATTR static uint32_t s_auto_snap_rtc_magic = 0;
RTC_DATA_ATTR static uint8_t s_auto_snap_rtc_enabled = 0;
RTC_DATA_ATTR static uint32_t s_boot_to_capture_est_ms = INITIAL_WAKE_ESTIMATE_MS;
RTC_DATA_ATTR static uint64_t s_previous_cycle_rtc_us = 0;
RTC_DATA_ATTR static uint32_t s_auto_snap_rtc_cycle_count = 0;
RTC_DATA_ATTR static uint32_t s_auto_snap_interval_ms = CAMERA_AUTO_SNAP_INTERVAL_MS;
RTC_DATA_ATTR static uint8_t s_capture_burst_enabled = 0;
RTC_DATA_ATTR static uint32_t s_run_schedule_rtc_magic = 0;
RTC_DATA_ATTR static uint8_t s_run_schedule_enabled = 0;
RTC_DATA_ATTR static uint16_t s_run_schedule_start_min = 8U * 60U;
RTC_DATA_ATTR static uint16_t s_run_schedule_stop_min = 22U * 60U;
RTC_DATA_ATTR static uint16_t s_run_schedule_days = 0;
RTC_DATA_ATTR static int32_t s_run_schedule_start_day = -1;
static program_state_machine_t s_program_state;
static capture_scheduler_t s_capture_scheduler;
static portMUX_TYPE s_program_state_lock = portMUX_INITIALIZER_UNLOCKED;
static bool s_comms_started;
static bool s_comms_power_suppressed;
static bool s_ble_started;
static bool s_c6_bridge_started;

static void program_publish(program_event_t event)
{
    event_breadcrumb_record(BREADCRUMB_PROGRAM_EVENT, (int32_t)event);
    portENTER_CRITICAL(&s_program_state_lock);
    esp_err_t err = program_state_dispatch(&s_program_state, event);
    portEXIT_CRITICAL(&s_program_state_lock);
    if (err != ESP_OK && err != ESP_ERR_INVALID_STATE) {
        (void)health_diag_record_fault("program_state", err);
    }
}

static void program_snapshot(program_state_t *state, uint32_t *transition_count)
{
    portENTER_CRITICAL(&s_program_state_lock);
    if (state != NULL) {
        *state = s_program_state.state;
    }
    if (transition_count != NULL) {
        *transition_count = s_program_state.transition_count;
    }
    portEXIT_CRITICAL(&s_program_state_lock);
}

#define AUTO_SNAP_RTC_MAGIC 0xA5015A10U
#define RUN_SCHEDULE_RTC_MAGIC 0x5C4ED001U

#define LOG_INTERVAL_MS       DEVICE_LOG_INTERVAL_MS
#define SD_RETRY_MS           DEVICE_SD_RETRY_MS
#define AUTO_SNAP_INTERVAL_MIN_S  (AUTO_SNAP_INTERVAL_MIN_MS / 1000U)
#define AUTO_SNAP_INTERVAL_MAX_S  (AUTO_SNAP_INTERVAL_MAX_MS / 1000U)
#define BLE_CONTROL_WAKE_GRACE_MS 1000U
#define RTC_LOG_PATH          SD_CAPTURE_DIR "/rtc_log.enc"
#define COMMAND_HELP_LINE \
    "CMDS: PROTOCOL [CLIENT_MAX_VERSION] | START_PROGRAM [INTERVAL_S] [BURST_0_1] | STOP_PROGRAM | SET_SCHEDULE HH:MM HH:MM DAYS [INTERVAL_S] [BURST_0_1] | START_SCHEDULE HH:MM HH:MM DAYS [INTERVAL_S] [BURST_0_1] | DISABLE_SCHEDULE | CAMERA_MODE [NORMAL|LOW_LIGHT] | DEEP_SLEEP | WAKE_UP | DEVICE_ON | DEVICE_OFF | GETTIME | SETTIME YYYY-MM-DD HH:MM:SS | IMG_SNAP | BURST_3S | MEDIA_EXPORT_KEY | USB_MSC_START | USB_MSC_STOP | IMG_COUNT | IMG_LIST | IMG_GETBIN <name> [offset] | IMG_GET64 <name> [offset] | IMG_GET <name> [offset] | IMG_DELETE_ALL | IMG_PAUSE | IMG_RESUME | V4L2_FORMATS | STATUS | HEALTH | SD_STATUS | TASK_STATS | CORE_STATS | SUMMARY_LIST | SUMMARY_GET <name> | SUMMARY_DELETE_ALL | HELP"


typedef struct {
    i2c_port_t i2c_port;
    gpio_num_t sda_gpio;
    gpio_num_t scl_gpio;
    uint32_t i2c_speed_hz;
    uint32_t log_interval_ms;
    uint32_t sd_retry_ms;
    const char *log_path;
    const char *log_password;
} app_config_t;

typedef struct app_context {
    rtc_t rtc;
    imu_orientation_t imu;
    sdmmc_card_t *card;
    uint32_t seq;
} app_context_t;

static void persist_program_state(bool enabled);

static void controller_enabled_changed(bool enabled)
{
    if (enabled) {
        ESP_LOGI(TAG,
                 "Auto capture schedule toggle: ON (button GPIO%d, burst=%u)",
                 CAMERA_BUTTON_GPIO,
                 (unsigned)s_capture_burst_enabled);
    } else {
        ESP_LOGI(TAG, "Auto capture schedule toggle: OFF (button GPIO%d)", CAMERA_BUTTON_GPIO);
    }
}

static void app_post(app_event_type_t type, bool value)
{
    event_breadcrumb_record(BREADCRUMB_APP_EVENT,
                            ((int32_t)type << 1) | (value ? 1 : 0));
    esp_err_t err = app_controller_post(type, value);
    if (err != ESP_OK) {
        ESP_LOGE(TAG, "Application event dropped: type=%d value=%d error=%s",
                 (int)type, value ? 1 : 0, esp_err_to_name(err));
        (void)health_diag_record_fault("app_event_queue", err);
    }
}

static void auto_snap_set_enabled(bool enabled)
{
    bool was_enabled = s_auto_snap_rtc_enabled != 0U;
    s_auto_snap_rtc_magic = AUTO_SNAP_RTC_MAGIC;
    s_auto_snap_rtc_enabled = enabled ? 1U : 0U;
    if (enabled && !was_enabled) {
        s_auto_snap_rtc_cycle_count = 0;
    }
    persist_program_state(enabled);
    app_post(APP_EVENT_SET_ENABLED, enabled);
}

static void media_set_capture_paused(bool paused)
{
    app_post(APP_EVENT_SET_PAUSED, paused);
    camera_set_capture_paused(paused);
}

static bool media_scheduler_is_paused(void)
{
    return app_controller_is_paused();
}

static void media_notify_transfer_state(bool active)
{
    event_breadcrumb_record(BREADCRUMB_TRANSFER, active ? 1 : 0);
    app_post(APP_EVENT_SET_TRANSFER_ACTIVE, active);
    program_publish(active ? PROGRAM_EVENT_TRANSFER_BEGIN : PROGRAM_EVENT_TRANSFER_END);
}

/* Polling beats GPIO interrupts here: button timing is slow, debounce is simple,
 * and polling keeps wake/sleep behavior easier to reason about. */
static void auto_snap_button_task(void *arg)
{
    (void)arg;
    watchdog_heartbeat_t heartbeat =
        watchdog_supervisor_register("snap_button", 2000);

    gpio_config_t io_cfg = {
        .pin_bit_mask = 1ULL << CAMERA_BUTTON_GPIO,
        .mode = GPIO_MODE_INPUT,
        .pull_up_en = GPIO_PULLUP_ENABLE,
        .pull_down_en = GPIO_PULLDOWN_DISABLE,
        .intr_type = GPIO_INTR_DISABLE,
    };

    esp_err_t cfg_err = gpio_config(&io_cfg);
    if (cfg_err != ESP_OK) {
        ESP_LOGE(TAG, "Button GPIO config failed: %s", esp_err_to_name(cfg_err));
        vTaskDelete(NULL);
        return;
    }

    int last_raw = gpio_get_level(CAMERA_BUTTON_GPIO);
    int stable_level = last_raw;
    int64_t last_change_us = esp_timer_get_time();

    ESP_LOGI(TAG,
             "Button armed on GPIO%d (active=%d, debounce=%dms)",
             CAMERA_BUTTON_GPIO,
             CAMERA_BUTTON_ACTIVE_LEVEL,
             CAMERA_BUTTON_DEBOUNCE_MS);

    while (true) {
        watchdog_supervisor_beat(heartbeat);
        int raw_level = gpio_get_level(CAMERA_BUTTON_GPIO);
        int64_t now_us = esp_timer_get_time();

        if (raw_level != last_raw) {
            last_raw = raw_level;
            last_change_us = now_us;
        }

        if (raw_level != stable_level &&
            (now_us - last_change_us) >= ((int64_t)CAMERA_BUTTON_DEBOUNCE_MS * 1000LL)) {
            stable_level = raw_level;
            if (stable_level == CAMERA_BUTTON_ACTIVE_LEVEL) {
                auto_snap_set_enabled(!app_controller_is_enabled());
            }
        }

        vTaskDelay(pdMS_TO_TICKS(CAMERA_BUTTON_POLL_MS));
    }
}

static const app_config_t APP_CONFIG = {
    .i2c_port = I2C_NUM_0,
    .sda_gpio = RTC_I2C_SDA_GPIO,
    .scl_gpio = RTC_I2C_SCL_GPIO,
    .i2c_speed_hz = RTC_I2C_PORT_SPEED_HZ,
    .log_interval_ms = LOG_INTERVAL_MS,
    .sd_retry_ms = SD_RETRY_MS,
    .log_path = RTC_LOG_PATH,
    .log_password = NULL,
};

static void app_cleanup(app_context_t *ctx);
static bool command_dispatch(app_context_t *ctx, char *cmd, command_reply_t *reply);
static void trim_newline(char *text);

#if CONFIG_BT_ENABLED
void ble_store_config_init(void);

#define BLE_CONTROL_DEVICE_NAME "RaphasCam"
#define BLE_CONTROL_SERVICE_UUID 0xFFF0
#define BLE_CONTROL_COMMAND_UUID 0xFFF1
#define BLE_CONTROL_RESPONSE_UUID 0xFFF2
#define BLE_CONTROL_MAX_COMMAND_LEN 127

static app_context_t *s_ble_app_ctx = NULL;
static uint8_t s_ble_own_addr_type = 0;
static uint16_t s_ble_conn_handle = 0;
static uint16_t s_ble_response_val_handle = 0;
static bool s_ble_connected = false;
static bool s_ble_response_subscribed = false;

static void ble_control_start_advertising(void);
static int ble_control_gap_event_cb(struct ble_gap_event *event, void *arg);

static void ble_control_notify_text(void *ctx, const char *data, size_t len)
{
    (void)ctx;

    if (!s_ble_connected || !s_ble_response_subscribed || len == 0) {
        return;
    }

    while (len > 0) {
        size_t chunk_len = len > 180 ? 180 : len;
        struct os_mbuf *om = ble_hs_mbuf_from_flat(data, chunk_len);
        if (om == NULL) {
            ESP_LOGW(TAG, "BLE notify allocation failed");
            return;
        }

        int rc = ble_gatts_notify_custom(
            s_ble_conn_handle,
            s_ble_response_val_handle,
            om
        );
        if (rc != 0) {
            ESP_LOGW(TAG, "BLE notify failed: rc=%d", rc);
            return;
        }

        data += chunk_len;
        len -= chunk_len;
    }
}

static int ble_control_access_cb(
    uint16_t conn_handle,
    uint16_t attr_handle,
    struct ble_gatt_access_ctxt *ctxt,
    void *arg
)
{
    (void)conn_handle;
    (void)attr_handle;
    (void)arg;

    if (ctxt->op != BLE_GATT_ACCESS_OP_WRITE_CHR) {
        return BLE_ATT_ERR_UNLIKELY;
    }

    if (s_ble_app_ctx == NULL) {
        return BLE_ATT_ERR_UNLIKELY;
    }

    char line[BLE_CONTROL_MAX_COMMAND_LEN + 1] = {0};
    uint16_t len = 0;
    int rc = ble_hs_mbuf_to_flat(ctxt->om, line, BLE_CONTROL_MAX_COMMAND_LEN, &len);
    if (rc != 0) {
        return BLE_ATT_ERR_INVALID_ATTR_VALUE_LEN;
    }
    line[len] = '\0';
    trim_newline(line);

    if (line[0] == '\0') {
        return 0;
    }

    ESP_LOGI(TAG, "BLE command: %s", line);
    command_reply_t reply = {
        .write_cb = ble_control_notify_text,
        .write_cb_ctx = NULL,
    };
    if (!command_dispatch(s_ble_app_ctx, line, &reply)) {
        command_reply_printf(&reply, "ERR Unknown command. Type HELP\n");
    }
    return 0;
}
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
void app_main(void)
{
    /* Boot order matters: persistent state and storage precede command tasks;
     * the shared RTC/I2C bus precedes camera initialization; background
     * capture starts only after controller state has been restored. */
    app_context_t ctx = {
        .rtc = {0},
        .imu = {0},
        .card = NULL,
        .seq = 0,
    };
    app_config_t runtime_config = APP_CONFIG;
    const app_config_t *cfg = &runtime_config;

    program_state_init(&s_program_state);
    log_security_config();

    esp_err_t camera_mode_err = startup_init_camera_mode();
    ESP_ERROR_CHECK(program_persistence_init());
    ESP_ERROR_CHECK(device_credentials_init());
    runtime_config.log_password = device_credentials_log_password();
    ESP_ERROR_CHECK(health_diag_init());
    event_breadcrumbs_init((int32_t)esp_reset_reason());
    ESP_ERROR_CHECK(watchdog_supervisor_init());
    program_publish(PROGRAM_EVENT_BOOT_COMPLETE);
    if (camera_mode_err != ESP_OK) {
        ESP_LOGE(TAG, "Camera mode load failed: %s; using compiled default",
                 esp_err_to_name(camera_mode_err));
    }

    const uint32_t wakeup_causes = esp_sleep_get_wakeup_causes();
    const bool timer_wake = (wakeup_causes & BIT(ESP_SLEEP_WAKEUP_TIMER)) != 0U;
    bool usb_present_at_boot = communications_usb_detect_is_active();
    bool rtc_program_state_valid =
        s_auto_snap_rtc_magic == AUTO_SNAP_RTC_MAGIC &&
        s_run_schedule_rtc_magic == RUN_SCHEDULE_RTC_MAGIC;
    /* Deep-sleep wakes use retained RTC state directly. Cold starts restore a
     * validated NVS record so a power interruption does not silently alter the
     * user's schedule, interval, or burst selection. */
    if (!rtc_program_state_valid) {
        s_auto_snap_rtc_magic = AUTO_SNAP_RTC_MAGIC;
        s_auto_snap_rtc_enabled = 0;
        s_auto_snap_rtc_cycle_count = 0;
        s_run_schedule_rtc_magic = RUN_SCHEDULE_RTC_MAGIC;
        s_run_schedule_enabled = 0;
        s_run_schedule_start_min = 8U * 60U;
        s_run_schedule_stop_min = 22U * 60U;
        s_run_schedule_days = 0;
        s_run_schedule_start_day = -1;

        program_persistence_state_t persisted = {0};
        bool persisted_found = false;
        esp_err_t persisted_err = program_persistence_load(&persisted, &persisted_found);
        if (persisted_err == ESP_OK && persisted_found &&
            persisted.schedule_start_minute < 1440U &&
            persisted.schedule_stop_minute < 1440U &&
            persisted.interval_ms >= AUTO_SNAP_INTERVAL_MIN_MS &&
            persisted.interval_ms <= AUTO_SNAP_INTERVAL_MAX_MS &&
            persisted.schedule_start_day >= -1) {
            s_auto_snap_rtc_enabled = persisted.enabled ? 1U : 0U;
            s_run_schedule_enabled = persisted.schedule_enabled ? 1U : 0U;
            s_run_schedule_start_min = persisted.schedule_start_minute;
            s_run_schedule_stop_min = persisted.schedule_stop_minute;
            s_run_schedule_days = persisted.schedule_days;
            s_run_schedule_start_day = persisted.schedule_start_day;
            s_auto_snap_interval_ms = persisted.interval_ms;
            s_capture_burst_enabled = persisted.burst_enabled ? 1U : 0U;
            ESP_LOGI(TAG,
                     "Restored program after power loss: enabled=%u schedule=%u interval=%u ms burst=%u",
                     (unsigned)s_auto_snap_rtc_enabled,
                     (unsigned)s_run_schedule_enabled,
                     (unsigned)s_auto_snap_interval_ms,
                     (unsigned)s_capture_burst_enabled);
        } else if (persisted_err != ESP_OK) {
            ESP_LOGE(TAG, "Persistent program state could not be loaded: %s",
                     esp_err_to_name(persisted_err));
        } else if (persisted_found) {
            ESP_LOGE(TAG, "Persistent program state is invalid; autonomous capture remains disabled");
        }
    }
    s_capture_scheduler = (capture_scheduler_t) {
        .enabled = s_run_schedule_enabled != 0,
        .start_minute = s_run_schedule_start_min,
        .stop_minute = s_run_schedule_stop_min,
        .days = s_run_schedule_days,
        .start_day = s_run_schedule_start_day,
    };
    bool initial_enabled = s_auto_snap_rtc_enabled != 0U;
    bool initial_forced_awake = usb_present_at_boot;
    /* Timer wakes suppress interactive radios unless policy explicitly allows
     * them. USB/interactive boots keep communications available for the GUI. */
    const communications_policy_input_t communications_input = {
        .timer_wake = timer_wake,
        .autonomous_capture_enabled = initial_enabled,
        .usb_present = usb_present_at_boot,
        .allow_on_timer_wake = CAMERA_COMMS_START_ON_TIMER_WAKE != 0,
    };
    bool start_communications =
        communications_policy_should_start(&communications_input);
    s_comms_power_suppressed = !start_communications;
    const app_controller_config_t controller_config = {
        .enabled = initial_enabled,
        .paused = false,
        .camera_ready = false,
        .forced_awake = initial_forced_awake,
        .enabled_changed = controller_enabled_changed,
    };
    ESP_ERROR_CHECK(app_controller_init(&controller_config));
    if (initial_enabled) {
        /* A deep-sleep wake or power-loss restore starts with an already-active
         * controller, so no command event exists to advance the lifecycle. */
        program_publish(PROGRAM_EVENT_WAKE);
    }
    if (timer_wake && initial_enabled) {
        s_skip_initial_idle_once = true;
        s_resume_from_timer_wakeup = true;
    } else {
        /* A flash/reset can retain an obsolete RTC estimate. Start the first
         * post-reset interval from the configured measured baseline. */
        s_boot_to_capture_est_ms = INITIAL_WAKE_ESTIMATE_MS;
    }
    ESP_LOGI(TAG,
             "Wake causes=0x%08" PRIx32 ", auto-schedule persisted state=%s, usb_detect=%d, gui_forced_awake=%d, wake->capture estimate=%u ms",
             wakeup_causes,
             app_controller_is_enabled() ? "ON" : "OFF",
             usb_present_at_boot ? 1 : 0,
             app_controller_is_forced_awake() ? 1 : 0,
             (unsigned)s_boot_to_capture_est_ms);

    setenv("TZ", "UTC0", 1);
    tzset();

    esp_err_t err = init_rtc(&ctx, cfg);
    if (err != ESP_OK) {
        ESP_LOGE(TAG, "RTC init failed: %s", esp_err_to_name(err));
        app_cleanup(&ctx);
        return;
    }

    err = mount_storage_with_retry(&ctx, cfg);
    if (err != ESP_OK) {
        ESP_LOGW(TAG,
                 "Storage unavailable at boot (%s); SD commands will fail fast until reboot with a card",
                 esp_err_to_name(err));
    }

    s_rtc_mutex = xSemaphoreCreateMutex();
    if (s_rtc_mutex == NULL) {
        ESP_LOGE(TAG, "Failed to create RTC mutex");
        app_cleanup(&ctx);
        return;
    }

    s_camera_rtc = &ctx.rtc;
    camera_set_timestamp_provider(camera_timestamp_provider);
    ESP_LOGI(TAG, "Init BMI323 I2C (SDA=%d, SCL=%d, INT1=%d, INT2=%d)",
             IMU_I2C_SDA_GPIO, IMU_I2C_SCL_GPIO, IMU_INT1_GPIO, IMU_INT2_GPIO);
    err = imu_orientation_init(&ctx.imu, IMU_I2C_PORT,
                               IMU_I2C_SDA_GPIO, IMU_I2C_SCL_GPIO,
                               IMU_I2C_PORT_SPEED_HZ);
    if (err != ESP_OK) {
        ESP_LOGW(TAG, "BMI323 init failed: %s; captures will log IMU status unavailable",
                 esp_err_to_name(err));
    }
    s_camera_imu = &ctx.imu;
    camera_set_orientation_provider(camera_orientation_provider);
    daily_summary_init(camera_timestamp_provider);
    camera_set_metrics_callbacks(camera_capture_metrics_cb, camera_save_metrics_cb);
    const media_transfer_camera_ops_t media_camera_ops = {
        .set_capture_paused = media_set_capture_paused,
        .wait_for_camera_idle = camera_wait_for_idle,
        .suspend_camera_stream = camera_suspend_stream,
        .resume_camera_stream = camera_resume_stream,
        .scheduler_is_paused = media_scheduler_is_paused,
        .notify_transfer_state = media_notify_transfer_state,
    };
    ESP_ERROR_CHECK(media_transfer_init(&media_camera_ops));

    {
        struct tm now = {0};
        if (read_time_with_fallback(&ctx.rtc, &now) == ESP_OK) {
            soft_clock_set_from_tm(&now);
        }
    }

    /* Keep the wired command path available on every wake, as in the known-
     * good Prototype-22 build. Radio/C6 startup remains governed by the power
     * policy below, so autonomous wakes do not pay the BLE startup cost. */
    if (xTaskCreate(serial_command_task, "serial_cmd", 16384, &ctx, 5, NULL) == pdPASS) {
        s_comms_started = true;
    } else {
        ESP_LOGE(TAG, "Failed to start serial command task");
        (void)health_diag_record_fault("serial_command_task", ESP_ERR_NO_MEM);
    }
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

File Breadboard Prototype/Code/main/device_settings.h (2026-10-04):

/* Board pin assignments and capture/storage policy constants. */

#pragma once

#include <stdbool.h>
#include <stdint.h>

#include "driver/gpio.h"
#include "driver/i2c_types.h"

/* Central device settings. Change these values before rebuilding firmware. */

/* Camera and image quality */
#define CAMERA_OUTPUT_RGB888             1
#define CAMERA_JPEG_QUALITY              90
#define CAMERA_JPEG_TIMEOUT_MS           30000
#define CAMERA_STREAM_WARMUP_FRAMES      10
#define CAMERA_ISP_BRIGHTNESS_PERCENT    54
#define CAMERA_JPEG_BACKEND_M2M          0

/* Capture scheduling and burst behavior */
#define CAMERA_BURST_WINDOW_MS           3000U
#define CAMERA_BURST_IMAGE_COUNT         3U
#define CAMERA_AUTO_SNAP_INTERVAL_MS     30000U
#define CAMERA_AUTO_SNAP_DEEP_SLEEP      1
#define CAMERA_AUTO_SNAP_INITIAL_IDLE_MS 1000U
#define INITIAL_WAKE_ESTIMATE_MS         1500U
#define AUTO_SNAP_INTERVAL_MIN_MS        5000U
#define AUTO_SNAP_INTERVAL_MAX_MS        3600000U
#define BOOT_TO_CAPTURE_EST_MIN_MS       500U
#define BOOT_TO_CAPTURE_EST_MAX_MS       20000U
#define CAPTURE_INTERVAL_FEEDBACK_DIVISOR 2U
#define CAPTURE_INTERVAL_MAX_ADJUST_MS    500U

/* Board pins */
#define CAMERA_USER_LED_GPIO             GPIO_NUM_3
#define CAMERA_USER_LED_ACTIVE_LEVEL     1
#define CAMERA_USER_LED_BLINK_MS          100U
#define CAMERA_PWDN_GPIO                 -1
#define CAMERA_BUTTON_GPIO               GPIO_NUM_5
#define CAMERA_BUTTON_ACTIVE_LEVEL       0
#define CAMERA_BUTTON_DEBOUNCE_MS         40U
#define CAMERA_BUTTON_POLL_MS             20U
#define CAMERA_USB_DETECT_GPIO            GPIO_NUM_NC
#define CAMERA_USB_DETECT_ACTIVE_LEVEL    1
#define RTC_I2C_SDA_GPIO                  GPIO_NUM_7
#define RTC_I2C_SCL_GPIO                  GPIO_NUM_8
#define RTC_I2C_PORT_SPEED_HZ             100000U

/* BMI323 orientation mapping. Device +Y points toward the wearable's top and
 * device +Z points out through the camera lens. Axis values are 0=X, 1=Y,
 * 2=Z; change these mappings/signs after a physical six-position check if the
 * breakout is mounted in another rotation. */
#define IMU_DEVICE_X_SENSOR_AXIS           0
#define IMU_DEVICE_X_SENSOR_SIGN           1
#define IMU_DEVICE_Y_SENSOR_AXIS           1
#define IMU_DEVICE_Y_SENSOR_SIGN           1
#define IMU_DEVICE_Z_SENSOR_AXIS           2
#define IMU_DEVICE_Z_SENSOR_SIGN           1
#define IMU_ORIENTATION_CARDINAL_THRESHOLD_MG 800
#define IMU_I2C_PORT                       I2C_NUM_1
#define IMU_I2C_SDA_GPIO                   GPIO_NUM_20
#define IMU_I2C_SCL_GPIO                   GPIO_NUM_36
#define IMU_I2C_PORT_SPEED_HZ              100000U
#define IMU_INT1_GPIO                      GPIO_NUM_22
#define IMU_INT2_GPIO                      GPIO_NUM_21

/* Optional P4/C6 bridge */
#define CAMERA_ESP_HOSTED_BLE_ENABLE     0
#define CAMERA_C6_BLE_BRIDGE_ENABLE      0
#define CAMERA_C6_BRIDGE_UART_PORT       1
#define CAMERA_C6_BRIDGE_UART_BAUD       115200
#define CAMERA_C6_BRIDGE_TX_GPIO         GPIO_NUM_NC
#define CAMERA_C6_BRIDGE_RX_GPIO         GPIO_NUM_NC
#define CAMERA_C6_WAKEUP_GPIO             GPIO_NUM_6
#define CAMERA_COMMS_START_ON_TIMER_WAKE   0

/* Storage, logging, and transfers */
#define DEVICE_LOG_INTERVAL_MS           600000U
#define DEVICE_SD_RETRY_MS               2000U
#define DEVICE_IMAGE_TX_CHUNK_BYTES      8192U
#define DEVICE_IMAGE_BINARY_CHUNK_BYTES  32768U
#define DEVICE_SD_CAPTURE_PATH            "/sdcard/captures"

typedef struct {
    uint32_t capture_interval_ms;
    uint32_t burst_window_ms;
    uint32_t initial_wake_estimate_ms;
    uint32_t jpeg_quality;
    uint32_t isp_brightness_percent;
    bool deep_sleep_enabled;
    const char *sd_capture_path;
} device_settings_t;

extern const device_settings_t g_device_settings;

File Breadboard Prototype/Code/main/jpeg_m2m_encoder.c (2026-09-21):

/* V4L2 memory-to-memory wrapper around the ESP32-P4 hardware JPEG encoder. */

#include "jpeg_m2m_encoder.h"

#include <fcntl.h>
#include <inttypes.h>
#include <string.h>
#include <sys/ioctl.h>
#include <sys/mman.h>
#include <unistd.h>

#include "esp_check.h"
#include "esp_log.h"
#include "esp_video_device.h"
#include "linux/v4l2-controls.h"
#include "linux/videodev2.h"

static const char *TAG = "jpeg_m2m";

static esp_err_t set_jpeg_quality(int fd, int quality)
{
    struct v4l2_ext_control control = {
        .id = V4L2_CID_JPEG_COMPRESSION_QUALITY,
        .value = quality,
    };
    struct v4l2_ext_controls controls = {
        .ctrl_class = V4L2_CID_JPEG_CLASS,
        .count = 1,
        .controls = &control,
    };

    if (ioctl(fd, VIDIOC_S_EXT_CTRLS, &controls) != 0) {
        ESP_LOGW(TAG, "JPEG quality control rejected; using driver default");
        return ESP_FAIL;
    }
    return ESP_OK;
}

esp_err_t jpeg_m2m_encoder_open(jpeg_m2m_encoder_t *ctx, int quality)
{
    ESP_RETURN_ON_FALSE(ctx, ESP_ERR_INVALID_ARG, TAG, "ctx is NULL");
    memset(ctx, 0, sizeof(*ctx));
    ctx->fd = -1;

    ctx->fd = open(ESP_VIDEO_JPEG_DEVICE_NAME, O_RDONLY);
    ESP_RETURN_ON_FALSE(ctx->fd >= 0, ESP_FAIL, TAG, "open %s failed", ESP_VIDEO_JPEG_DEVICE_NAME);

    struct v4l2_capability cap = {0};
    ESP_RETURN_ON_FALSE(ioctl(ctx->fd, VIDIOC_QUERYCAP, &cap) == 0,
                        ESP_FAIL, TAG, "QUERYCAP failed");
    ESP_LOGI(TAG, "V4L2 JPEG M2M opened: %s (%s)", cap.card, cap.driver);

    (void)set_jpeg_quality(ctx->fd, quality);
    return ESP_OK;
}

esp_err_t jpeg_m2m_encoder_start(jpeg_m2m_encoder_t *ctx,
                                 uint32_t width,
                                 uint32_t height,
                                 uint32_t input_pixfmt)
{
    ESP_RETURN_ON_FALSE(ctx && ctx->fd >= 0, ESP_ERR_INVALID_STATE, TAG, "encoder not open");
    if (ctx->started && ctx->width == width && ctx->height == height && ctx->input_pixfmt == input_pixfmt) {
        return ESP_OK;
    }
    if (ctx->started) {
        jpeg_m2m_encoder_close(ctx);
        ESP_RETURN_ON_ERROR(jpeg_m2m_encoder_open(ctx, 0), TAG, "reopen encoder");
    }

    ctx->width = width;
    ctx->height = height;
    ctx->input_pixfmt = input_pixfmt;

    struct v4l2_format fmt = {
        .type = V4L2_BUF_TYPE_VIDEO_OUTPUT,
        .fmt.pix = {
            .width = width,
            .height = height,
            .pixelformat = input_pixfmt,
        },
    };
    ESP_RETURN_ON_FALSE(ioctl(ctx->fd, VIDIOC_S_FMT, &fmt) == 0,
                        ESP_FAIL, TAG, "S_FMT output failed");

    struct v4l2_requestbuffers req = {
        .count = 1,
        .type = V4L2_BUF_TYPE_VIDEO_OUTPUT,
        .memory = V4L2_MEMORY_USERPTR,
    };
    ESP_RETURN_ON_FALSE(ioctl(ctx->fd, VIDIOC_REQBUFS, &req) == 0,
                        ESP_FAIL, TAG, "REQBUFS output failed");

    memset(&fmt, 0, sizeof(fmt));
    fmt.type = V4L2_BUF_TYPE_VIDEO_CAPTURE;
    fmt.fmt.pix.width = width;
    fmt.fmt.pix.height = height;
    fmt.fmt.pix.pixelformat = V4L2_PIX_FMT_JPEG;
    ESP_RETURN_ON_FALSE(ioctl(ctx->fd, VIDIOC_S_FMT, &fmt) == 0,
                        ESP_FAIL, TAG, "S_FMT capture failed");

    memset(&req, 0, sizeof(req));
    req.count = 1;
    req.type = V4L2_BUF_TYPE_VIDEO_CAPTURE;
    req.memory = V4L2_MEMORY_MMAP;
    ESP_RETURN_ON_FALSE(ioctl(ctx->fd, VIDIOC_REQBUFS, &req) == 0,
                        ESP_FAIL, TAG, "REQBUFS capture failed");

    struct v4l2_buffer buf = {
        .type = V4L2_BUF_TYPE_VIDEO_CAPTURE,
        .memory = V4L2_MEMORY_MMAP,
        .index = 0,
    };
    ESP_RETURN_ON_FALSE(ioctl(ctx->fd, VIDIOC_QUERYBUF, &buf) == 0,
                        ESP_FAIL, TAG, "QUERYBUF capture failed");

    ctx->capture_buffer = mmap(NULL, buf.length, PROT_READ | PROT_WRITE, MAP_SHARED,
                               ctx->fd, buf.m.offset);
    ESP_RETURN_ON_FALSE(ctx->capture_buffer != MAP_FAILED,
                        ESP_FAIL, TAG, "mmap capture failed");
    ctx->capture_buf_size = buf.length;

    ESP_RETURN_ON_FALSE(ioctl(ctx->fd, VIDIOC_QBUF, &buf) == 0,
                        ESP_FAIL, TAG, "QBUF capture failed");

    int type = V4L2_BUF_TYPE_VIDEO_CAPTURE;
    ESP_RETURN_ON_FALSE(ioctl(ctx->fd, VIDIOC_STREAMON, &type) == 0,
                        ESP_FAIL, TAG, "STREAMON capture failed");
    type = V4L2_BUF_TYPE_VIDEO_OUTPUT;
    ESP_RETURN_ON_FALSE(ioctl(ctx->fd, VIDIOC_STREAMON, &type) == 0,
                        ESP_FAIL, TAG, "STREAMON output failed");

    ctx->started = true;
    ESP_LOGI(TAG, "V4L2 JPEG M2M started: %" PRIu32 "x%" PRIu32 " input=0x%08" PRIx32,
             width, height, input_pixfmt);
    return ESP_OK;
}

esp_err_t jpeg_m2m_encoder_encode(jpeg_m2m_encoder_t *ctx,
                                  uint8_t *raw_buf,
                                  uint32_t raw_len,
                                  uint8_t **jpeg_buf,
                                  uint32_t *jpeg_len)
{
    ESP_RETURN_ON_FALSE(ctx && ctx->started, ESP_ERR_INVALID_STATE, TAG, "encoder not started");
    ESP_RETURN_ON_FALSE(raw_buf && raw_len && jpeg_buf && jpeg_len,
                        ESP_ERR_INVALID_ARG, TAG, "invalid encode args");

    struct v4l2_buffer out_buf = {
        .index = 0,
        .type = V4L2_BUF_TYPE_VIDEO_OUTPUT,
        .memory = V4L2_MEMORY_USERPTR,
        .m.userptr = (unsigned long)raw_buf,
        .length = raw_len,
        .bytesused = raw_len,
    };
    ESP_RETURN_ON_FALSE(ioctl(ctx->fd, VIDIOC_QBUF, &out_buf) == 0,
                        ESP_FAIL, TAG, "QBUF output failed");

    struct v4l2_buffer cap_buf = {
        .type = V4L2_BUF_TYPE_VIDEO_CAPTURE,
        .memory = V4L2_MEMORY_MMAP,
    };
    ESP_RETURN_ON_FALSE(ioctl(ctx->fd, VIDIOC_DQBUF, &cap_buf) == 0,
                        ESP_FAIL, TAG, "DQBUF capture failed");

    ESP_RETURN_ON_FALSE(ioctl(ctx->fd, VIDIOC_DQBUF, &out_buf) == 0,
                        ESP_FAIL, TAG, "DQBUF output failed");

    *jpeg_buf = ctx->capture_buffer;
    *jpeg_len = cap_buf.bytesused;
    return ESP_OK;
}
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

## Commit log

2026-09-21 Add development board and IMU firmware
    [imu_20260918_191904_00.csv, imu_20260918_191904_00_body_motion_summary.csv, imu_20260918_191904_00_detected_turns.csv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]
2026-09-21 Add breadboard firmware and Blur test code
    [000000_baseline_a0.jpg.csv, 000001_baseline_a0.jpg.csv, 000002_baseline_a0.jpg.csv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]
2026-10-02 Add BOMs, Data for Blur and IMU tests and KiCad 8.0 PCB schematics and layout
    [3000--3DModel-STEP-630548.iam, 3000.ipt, 7.ipt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]
2026-10-02 Added Low Light Analyser and TC66C Software and Analyser
    [2026-08-27-28-sc.csv, 2026-09-01-02-sc2336-burst.csv, Servo_Top.stl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]
2026-10-02 Add datasheets for PCB parts and updated README files
2026-10-04 Extract App from Development Board and Breaboard Prototype, works for both
    [partitions.csv, partitions.esp32.csv, partitions.esp32c2.csv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]
2026-10-04 Add STL files in respective CAD folders
    [Battery_seperator.stl, Case.stl, Cover.stl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]
2026-10-06 Add Images and gcode files
    [Battery_seperator.gcode.3mf, Case.gcode.3mf, Lid.gcode.3mf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]
2026-10-08 Added instrcutions and pictures on how to embedd the magnet and wireless coil into the PCB Case Lid
2026-10-11 Added instructions for ordering PCB from JLCPCB
2026-10-22 Added instructions on how to insert sliding door
2026-10-28 Updated CAD files and some code
